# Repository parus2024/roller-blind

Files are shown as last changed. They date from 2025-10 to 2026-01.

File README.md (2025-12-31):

# Parus-Roller-Blind: Умная Автоматизированная Автономная Роллета на ESPHome

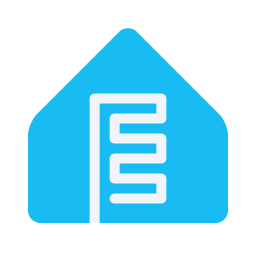
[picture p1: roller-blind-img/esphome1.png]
ESPHome Logo
 Home Assistant Logo
<p align="center">
    
    
    
    
</p>
## 🌟 Описание Проекта

**Parus-Roller-Blind** — это интеллектуальная система управления роллетами (шторами), построенная на базе ESPHome и интегрированная с Home Assistant. Проект позволяет автоматически и вручную управлять шторой в зависимости от времени суток, положения солнца или пользовательских настроек, с поддержкой энергосберегающего режима глубокого сна. Идеально подходит для умного дома, обеспечивая комфорт, безопасность и энергоэффективность. Без подзарядки обеспечивает автономную работу 1-2 месяца при ежедневном использовании. При замене шагового двигателя с драйвером на более мощные варианты способен работать с тяжелыми шторами. 

Основные возможности:
- **Автоматическое управление**: Штора управляется по расписанию (ввод времени) или по положению солнца (восход/закат), всегда поддерживая нужное состояние.
- **Ручное управление**: Через кнопку, ИК-пульт, Home Assistant, Яндекс (Алиса), Web страница.
- **Энергосбережение**: Глубокий сон ESP32-C3 с пробуждением по таймеру или кнопке.
- **Безопасность**: Предохранитель от перегрева мотора и тайм-аутов.
- **Мониторинг**: OLED-дисплей показывает статус, батарею, время и причины пробуждения.
- **Интеграция**: Полная совместимость с Home Assistant для удаленного управления и мониторинга.

Проект основан на ESP32-C3 (или любой ESP32), шаговом двигателе с драйвером A4988 и различных сенсорах. Код написан на ESPHome YAML с использованием substitutions для гибкой настройки.

---

## 🚀 Ключевые Функции

### Автоматизация
- **Режим "Солнце"**: Штора раборает по восходу и закату (с настраиваемым оффсетом угла солнца).
- **Режим "Время"**: Устанавливаемое время открытия и закрытия (например, 07:00–18:00).
- **Авто/Ручной режим**: Включение/отключение автоматического управления. В ручном режиме управляет шторой только при пробуждении по таймеру.
- **Глубокий сон**: ESP32 засыпает до следующего события, экономя батарею.
- **Автокоррекция**: Возможность коррекции положения шторы по геркону при открытии.

### Управление
- **Физическая кнопка**: Многофункциональная (открытие/закрытие, стоп, сон, справка, обучение).
- **ИК-пульт**: Программируется под любой код на любом ИК-пульте.
- **Home Assistant**: Полный контроль через API (открытие, закрытие, позиция).
- **Яндекс (Алиса)**: При подключении через Home Assistant (открытие, закрытие, позиция).
- **web страница**: Удаленное управление из любого места через любой браузер по ip адресу устройства.
- **Обучение**: Калибровка конечных точек шторы (открыто/закрыто).

### Безопасность и Мониторинг
- **Предохранитель**: Мониторинг тока (INA226) и тайм-аутов для предотвращения перегрева.
- **Геркон**: Датчик положения (для остановки при закрытии).
- **RTC DS1307**: Точное время даже без Wi-Fi.
- **OLED-дисплей**: Информация о статусе, батарее, времени до сна и причинах пробуждения.
- **Журнал загрузок**: История причин пробуждения (таймер, кнопка и т.д.).
- **Инфо о ESP**: Информация о ESP (причина перезагрузки, свободная память и т.д.).

### Энергосбережение
- Батарейное питание (18650) с мониторингом напряжения.
- Deep Sleep с пробуждением по таймеру или GPIO.
- Wi-Fi включается только при необходимости.
- Необходимо удалить LED питания с модуля ESP32C3
  
---

## 🛠 Компоненты и Аппаратура

### Основные Компоненты
- **Микроконтроллер**: ESP32-C3 (низкое энергопотребление, Wi-Fi/BLE).
- **Шаговый двигатель**: 28BYJ-48 5в в режиме биполярного подключения.
- **Контроллер заряда**: TP4056 -Контроллер заряда с защитой.
- **Драйвер двигателя**: драйвер A4988 (управление направлением, шагом, сном.
- **Дисплей**: OLED SSD1306 I2C (128x64, для отображения статуса).
- **Сенсоры**:
  - INA226(INA219): Мониторинг тока и напряжения мотора.
  - ADC: Напряжение батареи.
  - DS1307: RTC для автономного времени. Корректируется по времени из Home Assistant.
- **Питание**: Батарея 18650 (3.7V) с DC-DC преобразователем и возможностью зарядки через USB-C
- **DC-DC 3,7->8-12в**: Повышающий регулятор напряжения.
- **DC-DC 3.3в**: Понижающий линейный регулятор напряжения HT7333.
- **Мосфеты**: Мосфеты с обвязкой согласно вхемы.
- **Солнечная панель**: Солнечная панель 5,5-6в с током зарядки от 10мА.
- **Дополнительно**: ИК-приемник, кнопка, ИК-пульт (опционально).

### Схема Подключений (GPIO ESP32-C3)
- GPIO0: Кнопка управления (с pull-up, инвертированная).
- GPIO1: ADC для батареи.
- GPIO3: Шаг (step) для A4988.
- GPIO4: Направление (dir) для A4988 (инвертированное).
- GPIO2: Сон (sleep) для A4988.
- GPIO5: Питание мотора (GPIO switch).
- GPIO6: Геркон (pull-up, инвертированный).
- GPIO7: Питание дисплея (GPIO switch).
- GPIO8: LED (опционально).
- GPIO9: SDA I2C.
- GPIO10: SCL I2C.

### Программные Зависимости
- **ESPHome**: Версия 2024+ (поддержка глубокого сна и сенсоров).
- **Home Assistant**: Для интеграции (MQTT, API).
- **Шрифт**: Arial.ttf (для дисплея, загружается в ESPHome).

---

## 📋 Установка и Настройка

### 1. Подготовка Оборудования
- Соберите схему по GPIO выше, используя принципиальную электрическую схему 
- Установите ESPHome на ESP32-C3 (через USB или OTA).
- Подключите батарею и протестируйте питание.

### 2. Клонирование Репозитория
```bash
git clone https://github.com/parus2024/roller-blind.git
cd roller-blind
```

### 3. Настройка ESPHome
- Откройте файл `roller-blind.yaml` в VS Code с расширением ESPHome или в ESPHome Builder.
- Измените substitutions в начале файла под вашу конфигурацию:
  ```yaml
  substitutions:
    name: parus-roller-blind
    friendly_name: Parus Roller Blind
    friendly_name_short: parus_roller_blind
    version: "05.10.2025"
    device_ip: 192.168.x.x  # Ваш IP
    # ... остальные параметры (GPIO, скорости и т.д.)
  ```
- Загрузите нужные include папки (и укажите путь) или создайте свои необходимые базовые записи для ESPhome проекта.
- Загрузите шрифт `arial.ttf` в папку проекта (и укажите путь).

### 4. Интеграция с Home Assistant
- Добавьте устройство в HA через MQTT discovery.
- Используйте entities: cover, sensors, switches, buttons.
- Пример автоматизации: "Открыть штору на рассвете".

### 5. Обучение Шторы
- Включите режим обучения (длительное нажатие кнопки 6-10 сек).
- Следуйте инструкциям на дисплее: закройте штору, нажмите кнопку в нижней точке, затем откройте и нажмите в верхней.

---

## 🎮 Использование

### Управление Через Кнопку (GPIO0)
- **1 нажатие**: Открыть/Закрыть/Стоп (переключение направления).
- **2 нажатия**: Вкл/Выкл режим сон.
- **3 нажатия**: Справка (экран info).
- **4 нажатия**: Экран обучения.
- **5 нажатий**: Вкл/Выкл Wi-Fi.
- **6 нажатий**: Переключение страниц дисплея.
- **Длительное (3-5 сек) на главном экране**: Переключание режима авто/ручной.
- **Длительное (3-5 сек) на экране аварии**: Перезагрузка.
- **Длительное (6-10 сек)**: Вход в режим обучения.

### Управление Через ИК-Пульт
- **xxx**: обучить по логам.
- **Кнопка отключения**: Кнопка отключения ИК-датчика, если он не используется, что экономит до 50% в режиме сна.

### Дисплей (Страницы)
- **main_page**: Основной статус (время, позиция, батарея, сон).
- **learning**: Инструкции по обучению.
- **info**: Справка по кнопкам.
- **start_learning/open_setting/close_setting**: Шаги обучения.
- **finish**: Успех обучения.
- **sleeping**: Экран сна.
- **safety_alarm**: Авария (перегрев/тайм-аут).

### Настройки в Home Assistant
- **Sunrise/Sunset Offset**: Корректировка угла солнца.
- **Brightness**: Яркость дисплея.
- **Stepper Speed**: Скорость мотора.
- **Max Current/Timeout**: Безопасность.
- **COVER**: Ручная установка позиции.
- **Другие настройки**: Прочие многочисленные настройки.

---

## 🔧 Расширенная Настройка

### Substitutions
Настройте параметры в начале YAML:
- `pin_a/pin_b/pin_c`: GPIO для A4988.
- `max_speed/run_duration`: Скорость и время работы.
- `device_ip`: IP-адрес устройства.

### Глобальные Переменные
- `endstop`: Конечная точка (калибруется при обучении).
- `wifi_enabled`: Управление Wi-Fi.
- `sun_time`: Режим солнце/время.
- Прочие переменные.

### Логи и Отладка
- Включите `logger: debug` для логов.
- Мониторьте через ESPHome logs или HA.

### Энергосбережение
- Deep Sleep длится до следующего события (восход/закат или пользовательское время). Без подзарядки (солнечная батарея или USB-C) работает до 2 месяцев

---

## 📊 Скриншоты и Видео

- [yaml файл прошивки](parus-roller-blind.yaml)
- [внешний вид](roller-blind-img/roller-blind-v2_1.jpg)
- [внешний вид](roller-blind-img/roller-blind-v2_1.jpg)
- [статистика разрядки](roller-blind-img/battery_10day.png)
- [статистика зарядки](roller-blind-img/battery_30day.png)
- [Вид на окне](roller-blind-img/window.jpg)
- [Схема соединений](roller-blind-img/smart-roller-blind-shema.jpg)
- [Видео#1 YOUTUBE](https://youtu.be/TDQovWRaWWA)
- [Видео#2 YOUTUBE](https://youtu.be/KZsbmizrDjA)
- [Назначение геркона YOUTUBE](https://youtu.be/iwBEjguX0Tw)
- [Цепочка YOUTUBE](https://youtube.com/shorts/eKvNpj7ydDw)
- [Файлы для печати](roller-blind-3d)

---

## 🐛 Возможные Проблемы

- **Штора не двигается**: Проверьте питание мотора (GPIO5) и калибровку.
- **Нет времени**: Синхронизируйте RTC через HA или Wi-Fi.
- **Авария**: Проверьте ток (INA226) и тайм-ауты.
- **Wi-Fi не подключается**: Проверьте настройки `wifi.yaml`.

---

## 📄 Лицензия

Этот проект распространяется под лицензией MIT. Используйте на свой страх и риск.

---

##  Дополнительные источники информации

Телеграм канал https://t.me/parus_smart

---
## 🙏 Благодарности

- ESPHome сообществу за отличный фреймворк.
- Home Assistant за интеграцию.
- Вам за использование! Если проект полезен, поставьте ⭐ на GitHub.

---

*Создано с ❤️ ParusSmartHome. Версия: 05.10.2025*

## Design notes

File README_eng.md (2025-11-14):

# Smart-Roller-Blind: Smart Automated Standalone Roller Blind on ESPHome

ESPHome Logo Home Assistant Logo
<p align="center">
    
    
    
    
</p>

## 🌟 Project Description

**Parus-Roller-Blind** is an intelligent roller blind (curtain) control system built on ESPHome and integrated with Home Assistant. The project allows automatic and manual control of the blind depending on the time of day, sun position, or user settings, with support for energy-saving deep sleep mode. Perfect for smart homes, providing comfort, safety, and energy efficiency. Without recharging, it provides autonomous operation for 1-2 months with daily use. By replacing the stepper motor with a driver with more powerful options, it can work with heavy curtains.

Main features:
- **Automatic control**: The blind is controlled by schedule (time input) or by sun position (sunrise/sunset), always maintaining the desired state.
- **Manual control**: Via button, IR remote, Home Assistant, Yandex (Alice), Web page.
- **Energy saving**: Deep sleep of ESP32-C3 with wake-up by timer or button.
- **Safety**: Motor overheat protection and timeouts.
- **Monitoring**: OLED display shows status, battery, time, and wake-up reasons.
- **Integration**: Full compatibility with Home Assistant for remote control and monitoring.

The project is based on ESP32-C3 (or any ESP32), stepper motor with A4988 driver, and various sensors. The code is written in ESPHome YAML using substitutions for flexible configuration.

---

## 🚀 Key Features

### Automation
- **"Sun" mode**: The blind works according to sunrise and sunset (with adjustable sun angle offset).
- **"Time" mode**: Set opening and closing times (e.g., 07:00–18:00).
- **Auto/Manual mode**: Enable/disable automatic control. In manual mode, controls the blind only on timer wake-up.
- **Deep sleep**: ESP32 sleeps until the next event, saving battery.
- **Auto-correction**: Ability to correct blind position by reed switch on opening.

### Control
- **Physical button**: Multifunctional (open/close, stop, sleep, help, learning).
- **IR remote**: Programmable for any code on any IR remote.
- **Home Assistant**: Full control via API (open, close, position).
- **Yandex (Alice)**: When connected via Home Assistant (open, close, position).
- **Web page**: Remote control from anywhere via any browser at the device's IP address.
- **Learning**: Calibration of blind end points (open/closed).

### Safety and Monitoring
- **Protector**: Current monitoring (INA226) and timeouts to prevent overheating.
- **Reed switch**: Position sensor (for stopping on closing).
- **RTC DS1307**: Accurate time even without Wi-Fi.
- **OLED display**: Information on status, battery, time to sleep, and wake-up reasons.
- **Boot log**: History of wake-up reasons (timer, button, etc.).
- **ESP info**: Information about ESP (reboot reason, free memory, etc.).

### Energy Saving
- Battery power (18650) with voltage monitoring.
- Deep Sleep with wake-up by timer or GPIO.
- Wi-Fi turns on only when necessary.

---

## 🛠 Components and Hardware

### Main Components
- **Microcontroller**: ESP32-C3 (low power consumption, Wi-Fi/BLE).
- **Stepper motor**: 28BYJ-48 5V in bipolar connection mode.
- **Charge controller**: TP4056 charge controller with protection.
- **Motor driver**: A4988 driver (direction, step, sleep control).
- **Display**: OLED SSD1306 I2C (128x64, for status display).
- **Sensors**:
  - INA226 (INA219): Motor current and voltage monitoring.
  - ADC: Battery voltage.
  - DS1307: RTC for autonomous time. Corrected by time from Home Assistant.
- **Power**: 18650 battery (3.7V) with DC-DC converter and USB-C charging capability.
- **DC-DC 3.7->8-12V**: Boost voltage regulator.
- **DC-DC 3.3V**: Buck linear voltage regulator HT7333.
- **MOSFETs**: MOSFETs with appropriate circuitry.
- **Solar panel**: 5.5-6V solar panel with 10mA charging current.
- **Additional**: IR receiver, button, IR remote (optional).

### Wiring Diagram (ESP32-C3 GPIO)
- GPIO0: Control button (with pull-up, inverted).
- GPIO1: ADC for battery.
- GPIO3: Step (step) for A4988.
- GPIO4: Direction (dir) for A4988 (inverted).
- GPIO2: Sleep (sleep) for A4988.
- GPIO5: Motor power (GPIO switch).
- GPIO6: Reed switch (pull-up, inverted).
- GPIO7: Display power (GPIO switch).
- GPIO8: LED (optional).
- GPIO9: SDA I2C.
- GPIO10: SCL I2C.

### Software Dependencies
- **ESPHome**: Version 2024+ (deep sleep and sensor support).
- **Home Assistant**: For integration (MQTT, API).
- **Font**: Arial.ttf (for display, loaded in ESPHome).

---

## 📋 Installation and Setup

### 1. Hardware Preparation
- Assemble the circuit according to the GPIO above, using the electrical schematic.
- Install ESPHome on ESP32-C3 (via USB or OTA).
- Connect the battery and test the power.

### 2. Repository Cloning
```bash
git clone https://github.com/parus2024/roller-blind.git
cd roller-blind
```

### 3. ESPHome Configuration
- Open the `roller-blind.yaml` file in VS Code with ESPHome extension or in ESPHome Builder.
- Change substitutions at the beginning of the file to your configuration:
  ```yaml
  substitutions:
    name: parus-roller-blind
    friendly_name: Parus Roller Blind
    friendly_name_short: parus_roller_blind
    version: "05.10.2025"
    device_ip: 192.168.x.x  # Your IP
    # ... other parameters (GPIO, speeds, etc.)
  ```
- Load the necessary include folders (and specify the path) or create your own basic entries for the ESPHome project.
- Load the font `arial.ttf` into the project folder (and specify the path).

### 4. Home Assistant Integration
- Add the device to HA via MQTT discovery.
- Use entities: cover, sensors, switches, buttons.
- Example automation: "Open the blind at dawn".

### 5. Blind Learning
- Enable learning mode (long press button 6-10 sec).
- Follow display instructions: close the blind, press button at bottom point, then open and press at top.

---

## 🎮 Usage

### Control via Button (GPIO0)
- **1 press**: Open/Close/Stop (direction toggle).
- **2 presses**: Enable/Disable sleep mode.
- **3 presses**: Help (info screen).
- **4 presses**: Learning screen.
- **5 presses**: Enable/Disable Wi-Fi.
- **6 presses**: Switch display pages.
- **Long press (3-5 sec) on main screen**: Toggle auto/manual mode.
- **Long press (3-5 sec) on alarm screen**: Reboot.
- **Long press (6-10 sec)**: Enter learning mode.

### Control via IR Remote
- **xxx**: Learn from logs.
- **Disable button**: Disable IR sensor if not used, saving up to 50% in sleep mode.

### Display (Pages)
- **main_page**: Main status (time, position, battery, sleep).
- **learning**: Learning instructions.
- **info**: Button help.
- **start_learning/open_setting/close_setting**: Learning steps.
- **finish**: Learning success.
- **sleeping**: Sleep screen.
- **safety_alarm**: Alarm (overheat/timeout).

### Settings in Home Assistant
- **Sunrise/Sunset Offset**: Sun angle correction.
- **Brightness**: Display brightness.
- **Stepper Speed**: Motor speed.
- **Max Current/Timeout**: Safety.
- **COVER**: Manual position setting.
- **Other settings**: Numerous other settings.

---

## 🔧 Advanced Configuration

### Substitutions
Configure parameters at the beginning of YAML:
- `pin_a/pin_b/pin_c`: GPIO for A4988.
- `max_speed/run_duration`: Speed and runtime.
- `device_ip`: Device IP address.

### Global Variables
- `endstop`: End point (calibrated during learning).
- `wifi_enabled`: Wi-Fi control.
- `sun_time`: Sun/time mode.
- Other variables.

### Logs and Debugging
- Enable `logger: debug` for logs.
- Monitor via ESPHome logs or HA.

### Energy Saving
- Deep Sleep lasts until the next event (sunrise/sunset or custom time). Without recharging (solar panel or USB-C), operates up to 2 months.

---

## 📊 Screenshots and Videos

*(Add screenshots of the display, HA dashboard, or demo videos here)*

- [Firmware yaml file](smart-roller-blind.yaml)
- [Appearance](roller-blind-img/roller-blind-v2_1.jpg)
- [Appearance](roller-blind-img/roller-blind-v2_1.jpg)
- [Window view](roller-blind-img/window.jpg)
- [Wiring diagram](roller-blind-img/smart-roller-blind-shema.jpg)
- [Video#1 YOUTUBE](https://youtu.be/TDQovWRaWWA)
- [Video#2 YOUTUBE](https://youtu.be/KZsbmizrDjA)
- [3D print files](roller-blind-3d)

---

## 🐛 Possible Issues

- **Blind doesn't move**: Check motor power (GPIO5) and calibration.
- **No time**: Sync RTC via HA or Wi-Fi.
- **Alarm**: Check current (INA226) and timeouts.
- **Wi-Fi doesn't connect**: Check `wifi.yaml` settings.

For help, open an issue in the repository.

---

## 📄 License

This project is distributed under the MIT license. Use at your own risk.

---

## Additional Information Sources

Telegram channel https://t.me/parus_smart

---
## 🙏 Acknowledgments

- ESPHome community for the great framework.
- Home Assistant for integration.
- You for using it! If the project is helpful, give it a ⭐ on GitHub.

---

*Created with ❤️ ParusSmartHome. Version: 05.10.2025*

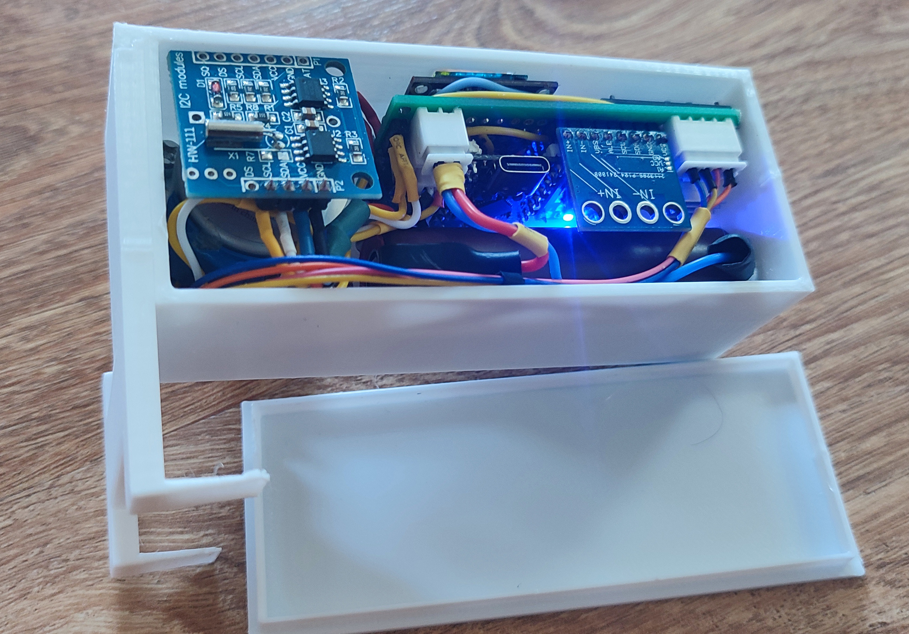
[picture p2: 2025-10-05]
roller-blind-img/roller-blind-v2_2.jpg

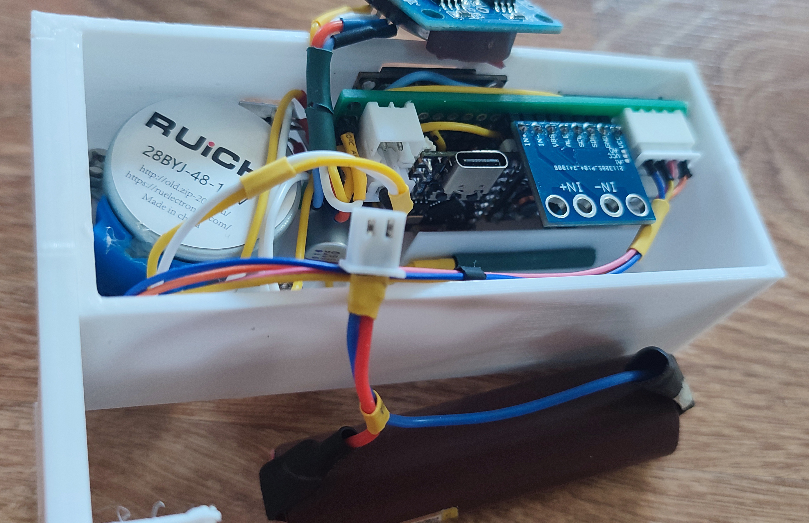
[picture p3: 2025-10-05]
roller-blind-img/roller-blind-v2_1.jpg

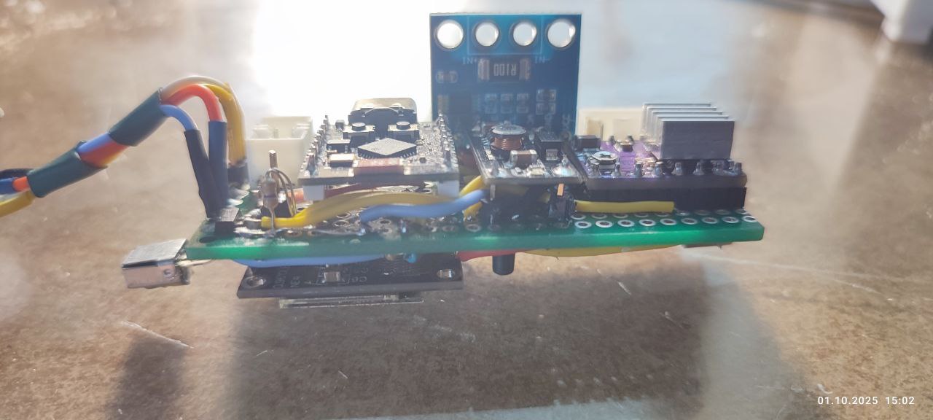
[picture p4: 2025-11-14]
roller-blind-img/roller-blind-v2_5.jpg

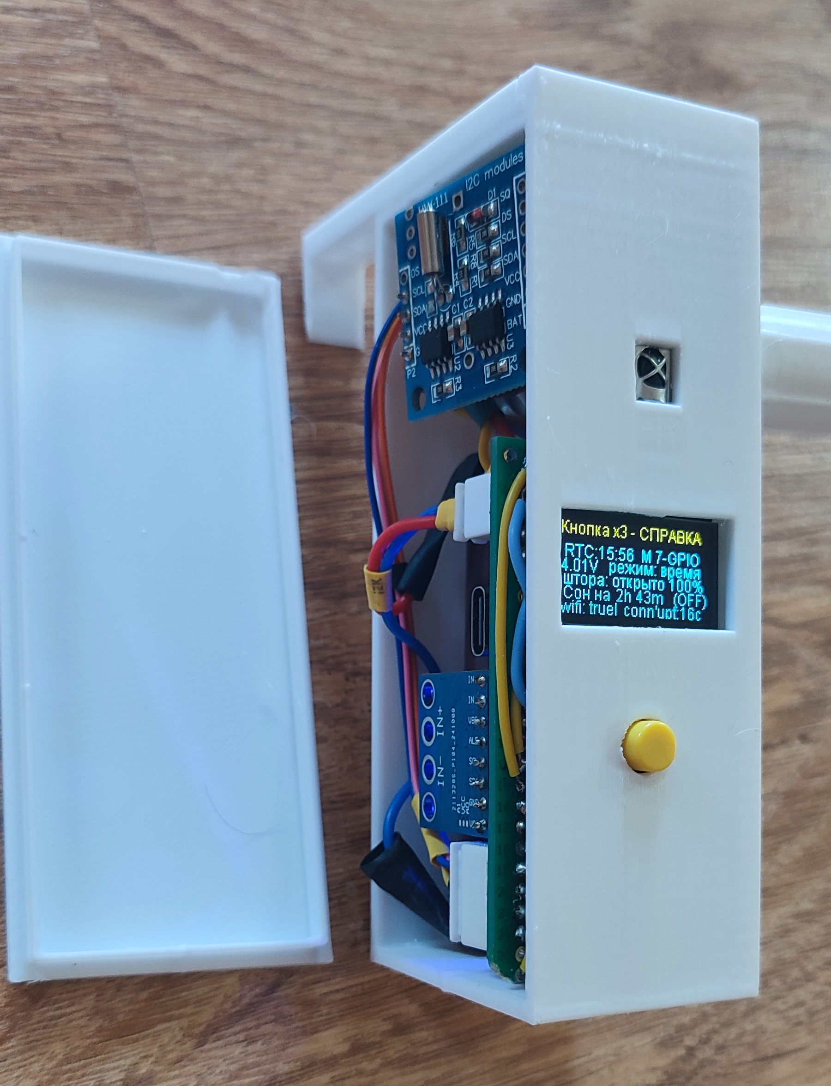
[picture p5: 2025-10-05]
roller-blind-img/roller-blind-v2_4.jpg

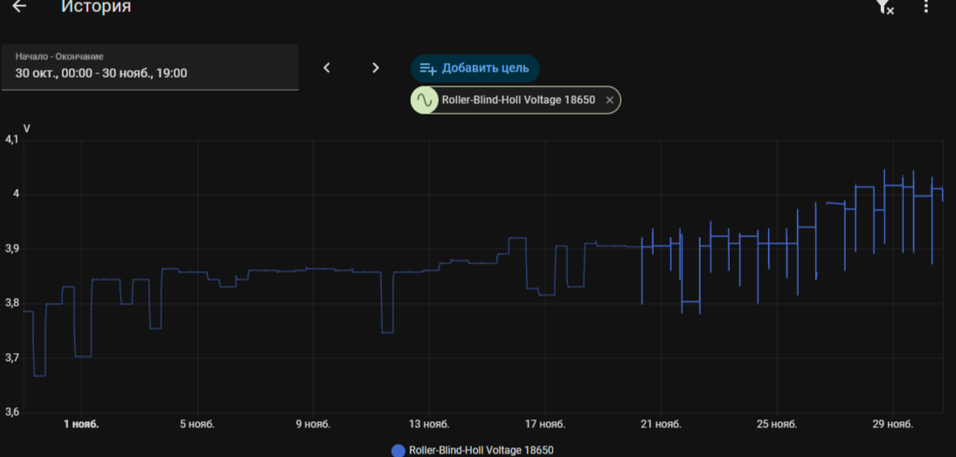
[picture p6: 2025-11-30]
roller-blind-img/battery_30day.png

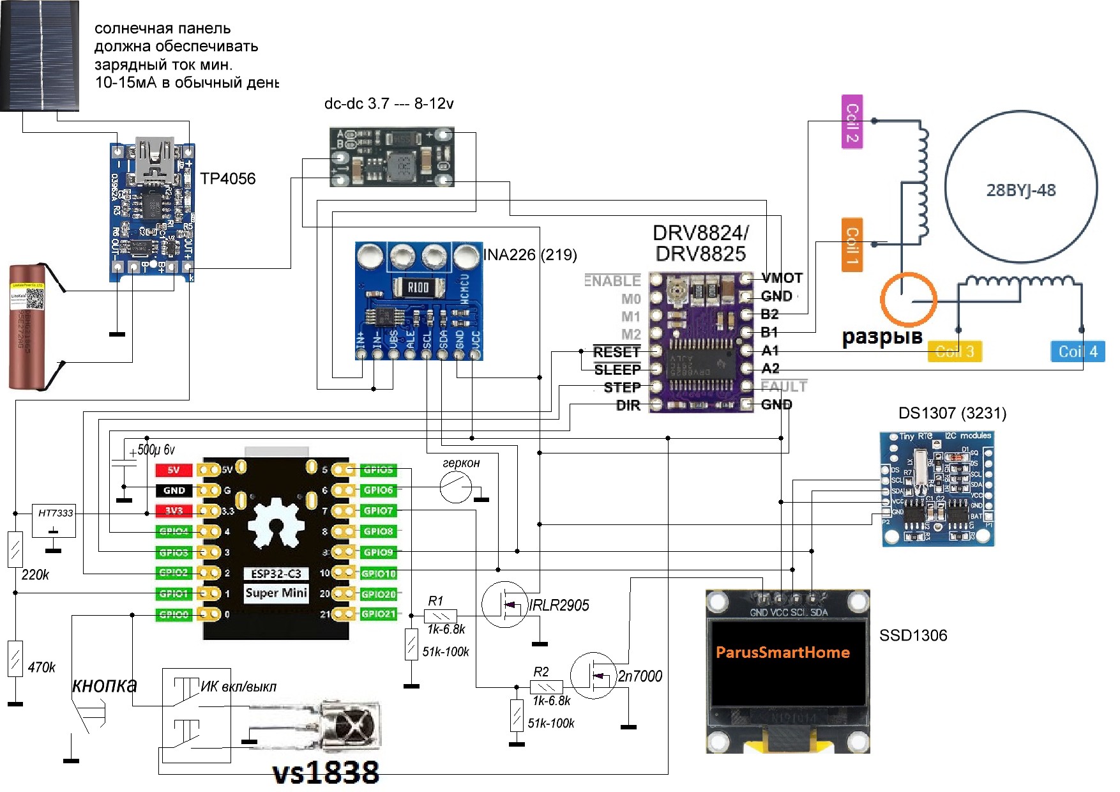
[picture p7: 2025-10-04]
roller-blind-img/smart-roller-blind-shema.jpg

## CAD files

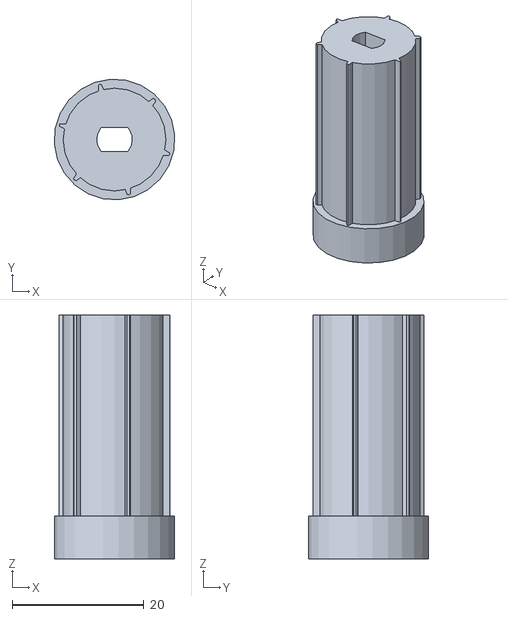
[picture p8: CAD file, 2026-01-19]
roller-blind-3d/adapter2.stl
18.3 x 18.3 x 37.1

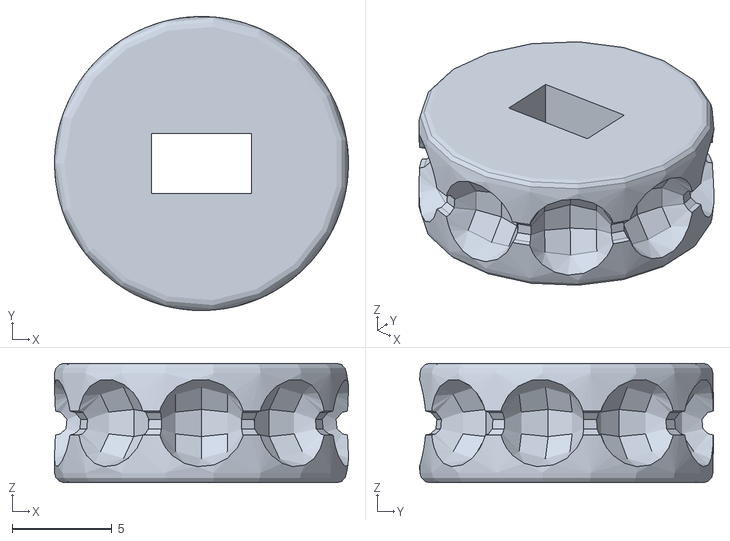
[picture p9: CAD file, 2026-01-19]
roller-blind-3d/rolls_chain_adapter30_12_2025.stl
14.8 x 14.8 x 6.00

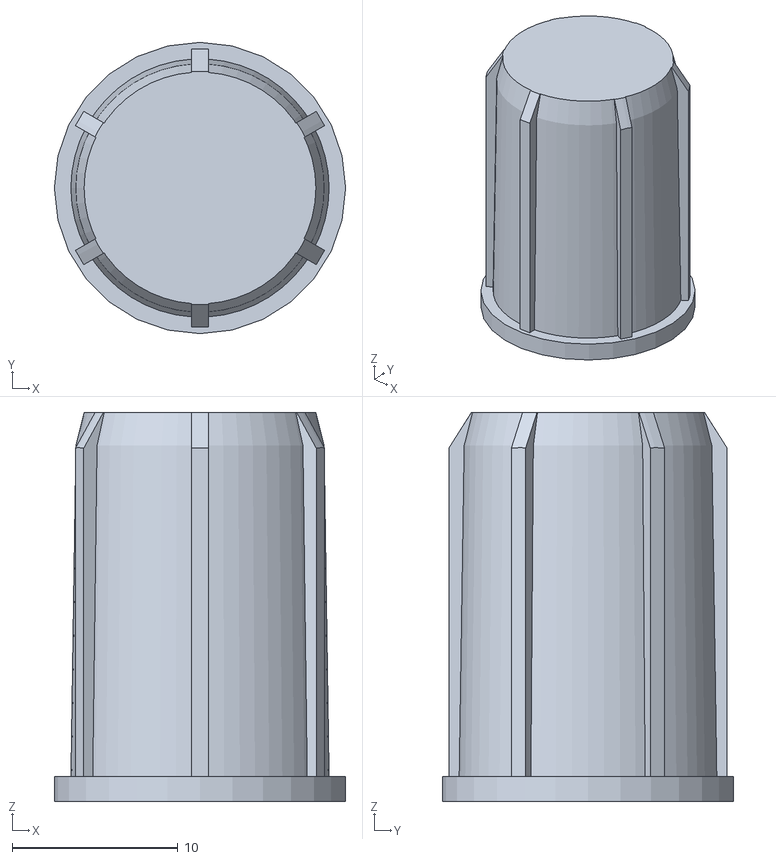
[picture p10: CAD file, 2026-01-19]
roller-blind-3d/adapter1.stl
17.6 x 17.6 x 23.5

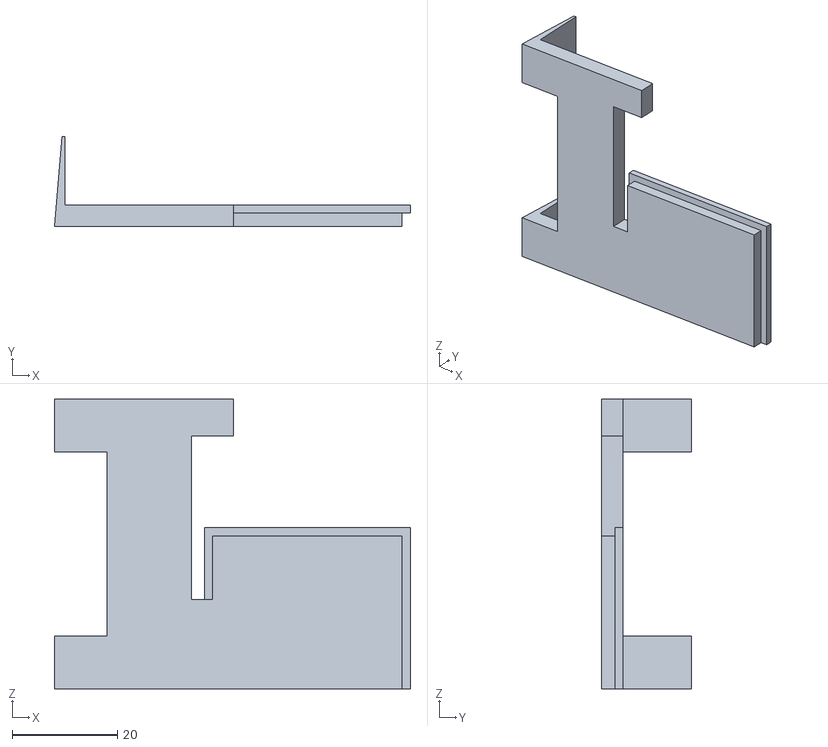
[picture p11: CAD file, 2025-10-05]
roller-blind-3d/box_hut03_10_2025.stl
67.6 x 17.0 x 55.0

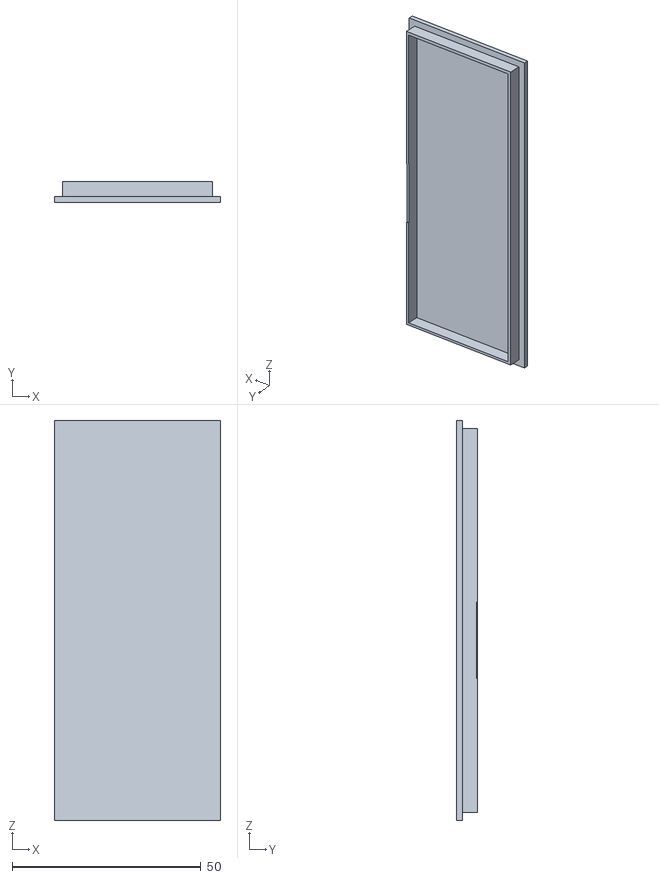
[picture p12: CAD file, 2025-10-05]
roller-blind-3d/roller_deck_new01_10_2025.stl
44.0 x 5.50 x 106.0

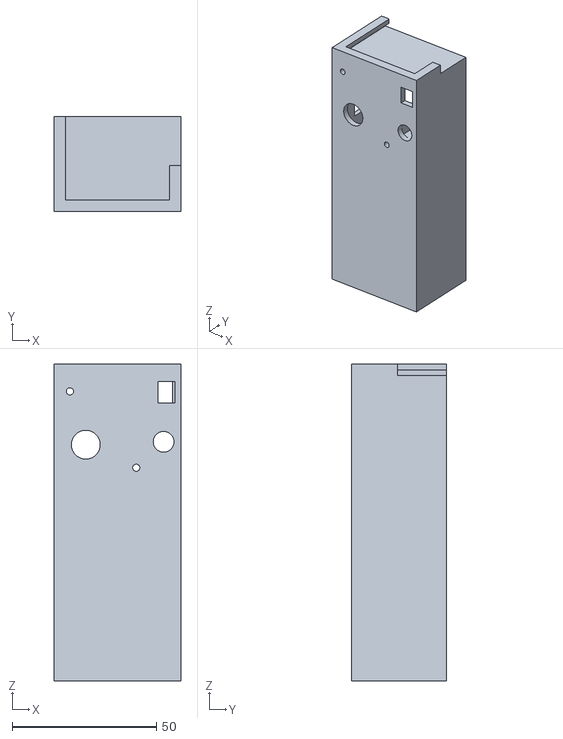
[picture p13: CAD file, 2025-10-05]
roller-blind-3d/roller_box_new03_10_2025.stl
44.0 x 33.0 x 110.0

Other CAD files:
roller-blind-3d/box_hut03_10_2025.ipt
roller-blind-3d/roller_box_new03_10_2025.ipt
roller-blind-3d/roller_deck_01_10_2025.ipt

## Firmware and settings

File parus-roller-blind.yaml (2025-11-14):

substitutions:
  name: parus-roller-blind
  friendly_name: Parus Roller Blind
  friendly_name_short: parus_roller_blind
  version: "05.10.2025"
  device_ip: 192.168.0.214
  reboot_timeout: 0s
  pin_led: GPIO8
  sda1: GPIO9
  scl1: GPIO10
  mystepper: my_stepper
  pin_a: GPIO3 # Шаг
  pin_b: GPIO4 # Направление
  pin_c: GPIO2 # Sleep/reset
  max_speed: 600 steps/s
  run_duration: 120s
  sleep_duration: 30s

<<: !include attach/common/esphome.yaml 
<<: !include attach/common/esp/esp32_c3_idf.yaml
<<: !include attach/common/logger/debug.yaml
<<: !include attach/common/api.yaml
<<: !include attach/common/ota.yaml
<<: !include attach/common/wifi.yaml
<<: !include attach/common/web/web_server3.yaml
<<: !include attach/common/bus/i2c_a.yaml
<<: !include attach/common/sun.yaml
packages:
  common: !include attach/packages/standart.yaml
globals:
  - id: time_received # Флаг получения времени от НА
    type: bool
    initial_value: "false"
  - id: time_received_homeassistant # Флаг получения времени от homeassistant
    type: bool
    initial_value: "false"
  - id: next_sleep_duration # Переменная продолжительности сна перед засыпанием в любой момент времени
    type: uint64_t
    initial_value: '0'
  - id: bootCount # Переменная подсчета количества загрузок\выхода из сна
    type: int
    restore_value: yes
    initial_value: '0'
  - id: bootHistory # Переменная причин загрузок\выхода из сна
    type: std::string
    restore_value: yes
    initial_value: '""'
  - id: last_wakeup_reason # Переменная причины последней загрузки\выхода из сна
    type: int
    initial_value: '0' # Изначально 0 (неопределённая причина)
  - id: ${mystepper}_global # Целое число для хранения позиции шагового двигателя на случай перезагрузки
    type: unsigned long
    restore_value: True
    initial_value: '0'
  - id: openclosed # Глобальная переменная, указывает состояние роллеты (1 = открыто, 0 = закрыто).
    type: bool
    restore_value: True
    initial_value: '0'
  - id: last_direction
    type: int
    initial_value: '0' # 0 = открытие, 1 = закрытие (начнём с открытия)
  - id: endstop # Переменная для хранения конечной точки  (полностью открыто).(насколько далеко двигаться шаговому двигателю)
    type: unsigned long
    restore_value: True
    initial_value: '1000'
  - id: settingmode # Глобальная переменная, указывает этап настройки (1 = закрытие, 2 = открытие, 3 = завершение).
    type: int
    restore_value: no
    initial_value: '0'
  - id: countdown # Обратный отсчет до сна
    type: int
    initial_value: '0'
  - id: wifi_enabled
    type: bool
    restore_value: yes
    initial_value: 'true' # Начальное значение 

  - id: motor_running
    type: bool
    initial_value: 'false'
  - id: safety_triggered
    type: bool
    initial_value: 'false'
  - id: last_movement_start # Можно переиспользовать для start_time
    type: uint32_t # Изменил на uint32_t для millis()
    initial_value: '0'
font:
  - file: "fonts/arial.ttf"
    id: arial_12
    size: 12
    glyphs: |-
      |#~*<>!'"%/()+=,-_.:°0123456789АБВГДЕЁЖЗИЙКЛМНОПРСТУФХЦЧШЩЬЫЪЭЮЯABCDEFGHIJKLMNOPQRSTUVWXYZ абвгдеёжзийклмнопрстуфхцчшщьыъэюяabcdefghijklmnopqrstuvwxyz
display:
  - platform: ssd1306_i2c
    model: "SSD1306 128x64"
    address: 0x3C
    i2c_id: bus_a
    id: my_display
    pages:
      - id: main_page
        lambda: |-
          it.print(0, 0, id(arial_12), TextAlign::TOP_LEFT, "Кнопка х3 - СПРАВКА");
          // Текущее время ds1307
          auto time = id(ds1307_time).now(); // ESPTime
          it.printf(0, 14, id(arial_12), TextAlign::TOP_LEFT, " RTC:%02d:%02d", id(ds1307_time).now().hour, id(ds1307_time).now().minute);
          // Индикатор режима: A (auto) или M (manual)
          if (id(auto_rolls).state) {
            it.print(68, 14, id(arial_12), TextAlign::TOP_LEFT, "A");
          } else {
            it.print(68, 14, id(arial_12), TextAlign::TOP_LEFT, "M");
          }
          // Причина пробуждения из text_sensor
          std::string wakeup_text = id(wakeup_cause_text).state; // Читаем напрямую из сенсора
          it.printf(80, 14, id(arial_12), TextAlign::TOP_LEFT, wakeup_text.c_str());

          // режим солнце/время
          if (!id(sun_time).state) {
          it.print(40, 23, id(arial_12), TextAlign::TOP_LEFT, "режим: солнце");
          }
          else {
          it.print(40, 23, id(arial_12), TextAlign::TOP_LEFT, "режим: время");
          }
          it.printf(0, 24, id(arial_12), TextAlign::TOP_LEFT, "%.2fV", id(battery_voltage).state);
          // положение шторы
          float pos_norm = float(id(${mystepper}_global)) / float(id(endstop));
          if (id(${mystepper}).current_position == 0) {
            it.printf(2, 33, id(arial_12), TextAlign::TOP_LEFT, "штора: закрыта");
          } else {
            it.printf(2, 33, id(arial_12), TextAlign::TOP_LEFT, "штора: открыто %.0f%%", pos_norm * 100);
          }
          it.print(2, 43, id(arial_12), TextAlign::TOP_LEFT, "Сон на");
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

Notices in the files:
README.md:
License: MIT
